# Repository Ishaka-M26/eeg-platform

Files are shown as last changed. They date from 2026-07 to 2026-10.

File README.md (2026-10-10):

# EEG Platform

A custom multichannel EEG acquisition platform for exploring real-time EEG processing and closed-loop neurotechnology.

<p align="center">
  
</p>

**Prototype setup: EEG electrodes, custom ADS1299 interface board, and Zybo Zynq-7000.**

<p align="center">
  
</p>

**Hardware connections and major components of the current prototype.**

# Overview
A custom EEG acquisition platform for real-time neural signal measurement and future closed-loop neurostimulation research.

The system is built around a custom ADS1299-based EEG frontend and a Zynq-based processing platform.  
The current focus is reliable multichannel EEG acquisition, real-time data transfer, and system-level validation from analog input to digital processing.

---

## System Overview

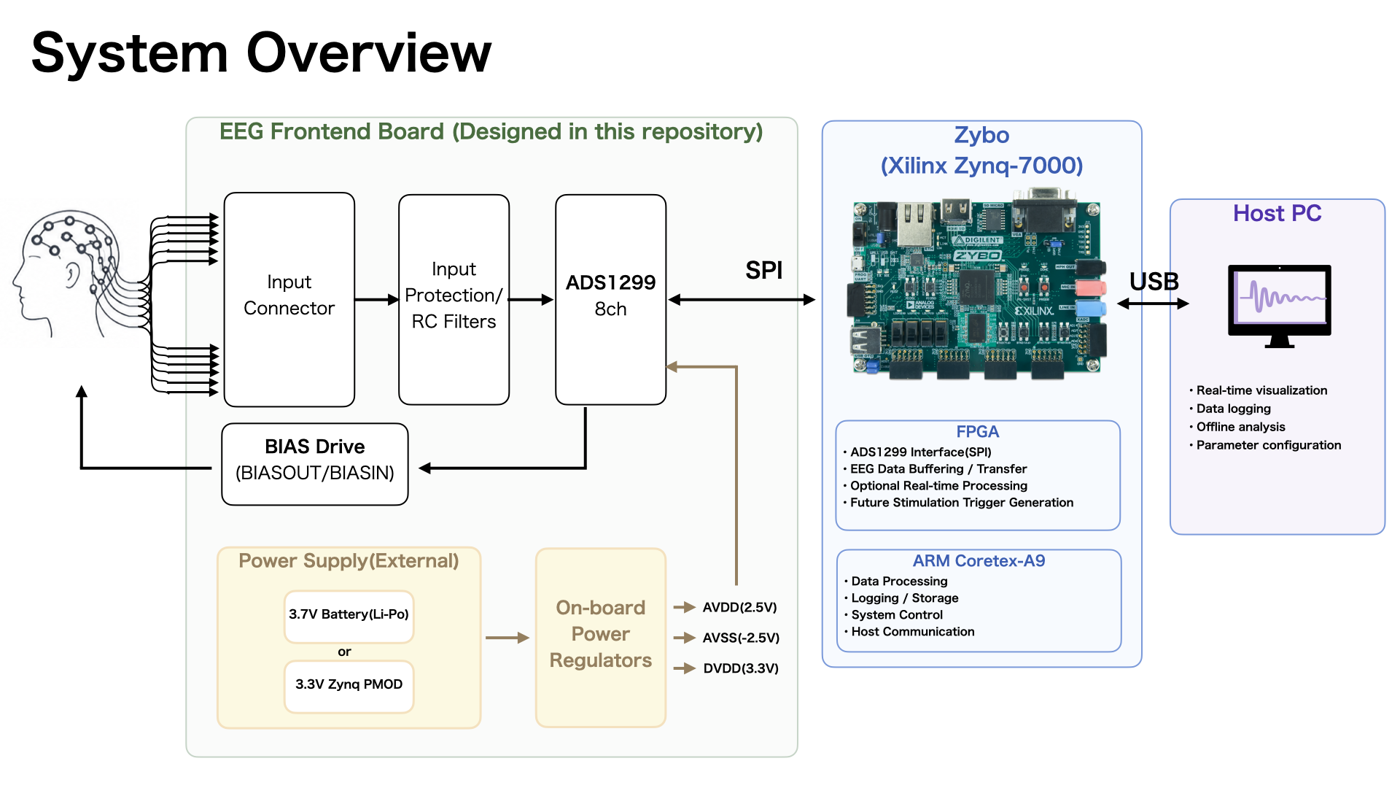
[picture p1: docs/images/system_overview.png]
EEG Platform System Overview


The platform consists of:

- **Custom EEG Frontend Board**
  - ADS1299-based multichannel EEG acquisition
  - Input protection
  - On-board power regulation
  - BIAS / common-mode feedback
  - SPI interface to the processing platform

- **Zybo Z7 / Zynq Platform**
  - ADS1299 SPI interface
  - EEG data reception and transfer
  - Optional real-time processing
  - Future stimulation trigger generation

- **Host PC**
  - Visualization
  - Data logging
  - Offline analysis
  - System configuration

The long-term goal is to extend this platform toward a closed-loop architecture in which brain-state information is estimated in real time and used to control non-invasive stimulation.

---

## Custom EEG Frontend

The EEG frontend board is designed specifically for this project.

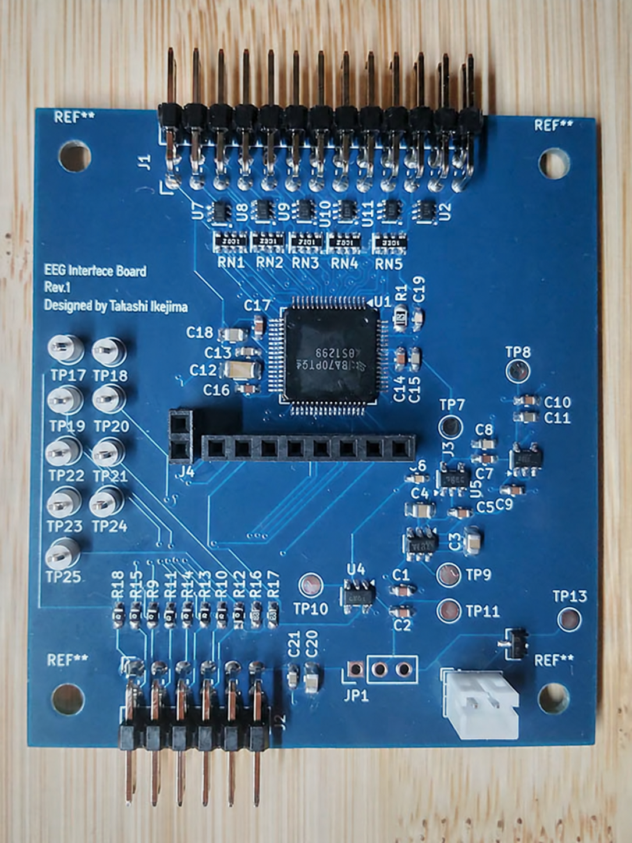
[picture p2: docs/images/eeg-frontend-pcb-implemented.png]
EEG Frontend PCB


It is based on the **ADS1299**, an 8-channel, 24-bit analog front end for biopotential measurement.  
The board integrates EEG input protection, analog acquisition, power regulation, and the digital interface required for connection to the Zynq platform.

The KiCad schematic and PCB design files are available in:

```text
hardware/kicad/eeg-frontend/
```

---

## Project Direction

The project is being developed in stages:

1. **EEG frontend design and fabrication**
2. **Multichannel EEG acquisition**
3. **Zynq-based real-time data handling**
4. **Signal processing and brain-state estimation**
5. **Future closed-loop stimulation integration**

The initial objective is not to build a complete clinical neurostimulation device, but to establish a reliable hardware and software platform for real-time EEG-based neural interface research.

---

## Repository Structure

```text
eeg-platform/
├── docs/
│   └── images/
│       ├── eeg-frontend-3d.png
│       ├── eeg-frontend-pcb.png
│       └── system_overview.png
│
├── hardware/
│   └── kicad/
│       ├── eeg-frontend/
│       └── reference_design/
│
└── README.md
```

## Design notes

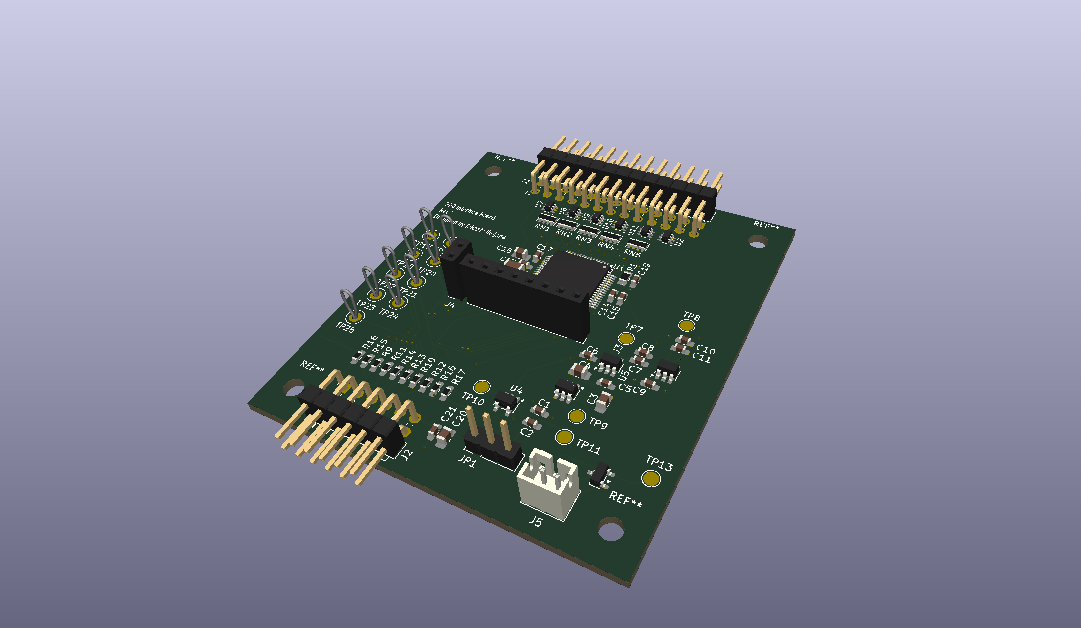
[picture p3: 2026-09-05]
docs/images/eeg-frontend-3d.png

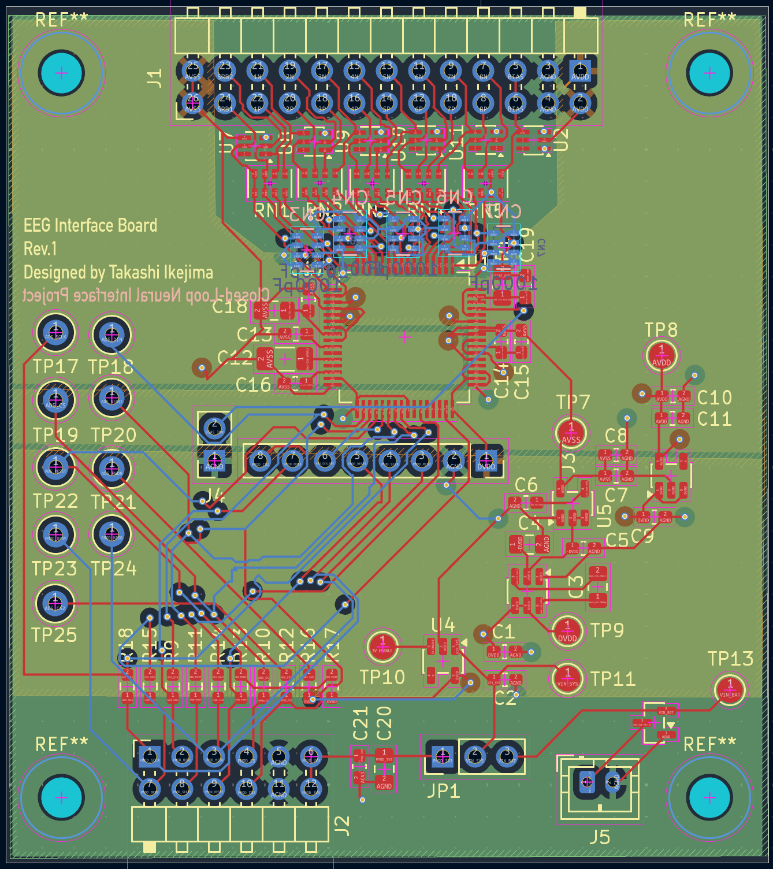
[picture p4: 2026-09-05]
docs/images/eeg-frontend-pcb.png

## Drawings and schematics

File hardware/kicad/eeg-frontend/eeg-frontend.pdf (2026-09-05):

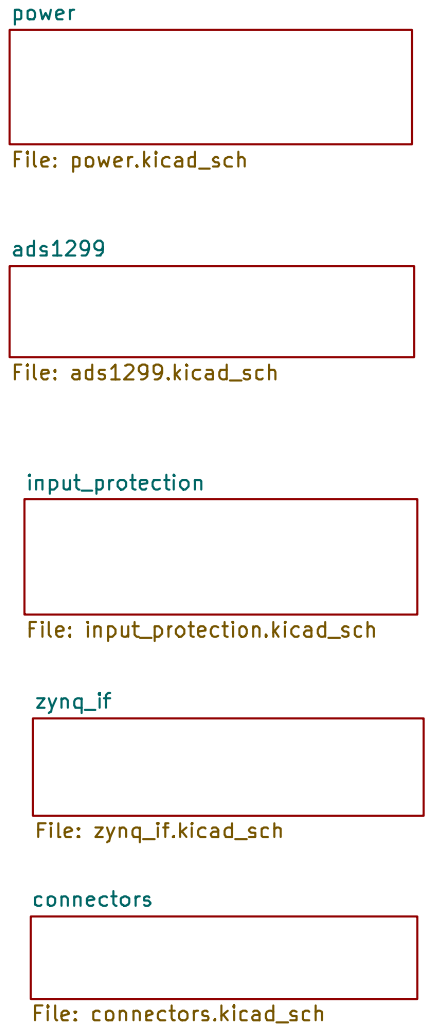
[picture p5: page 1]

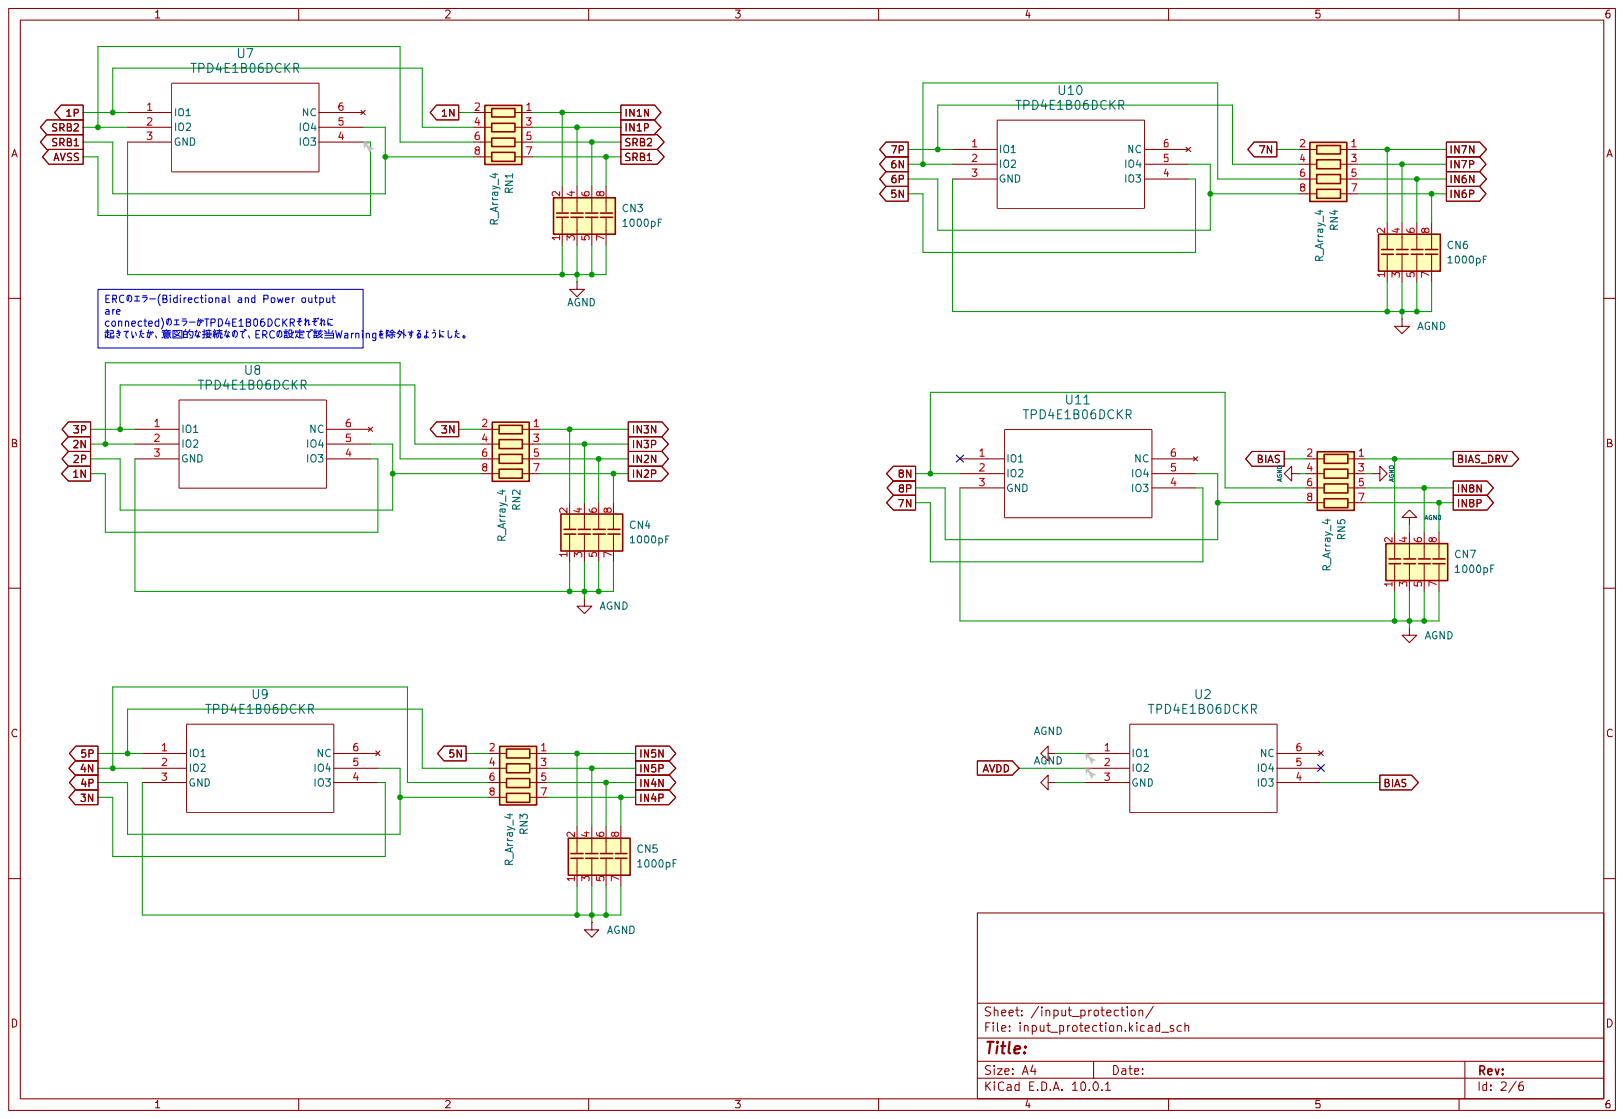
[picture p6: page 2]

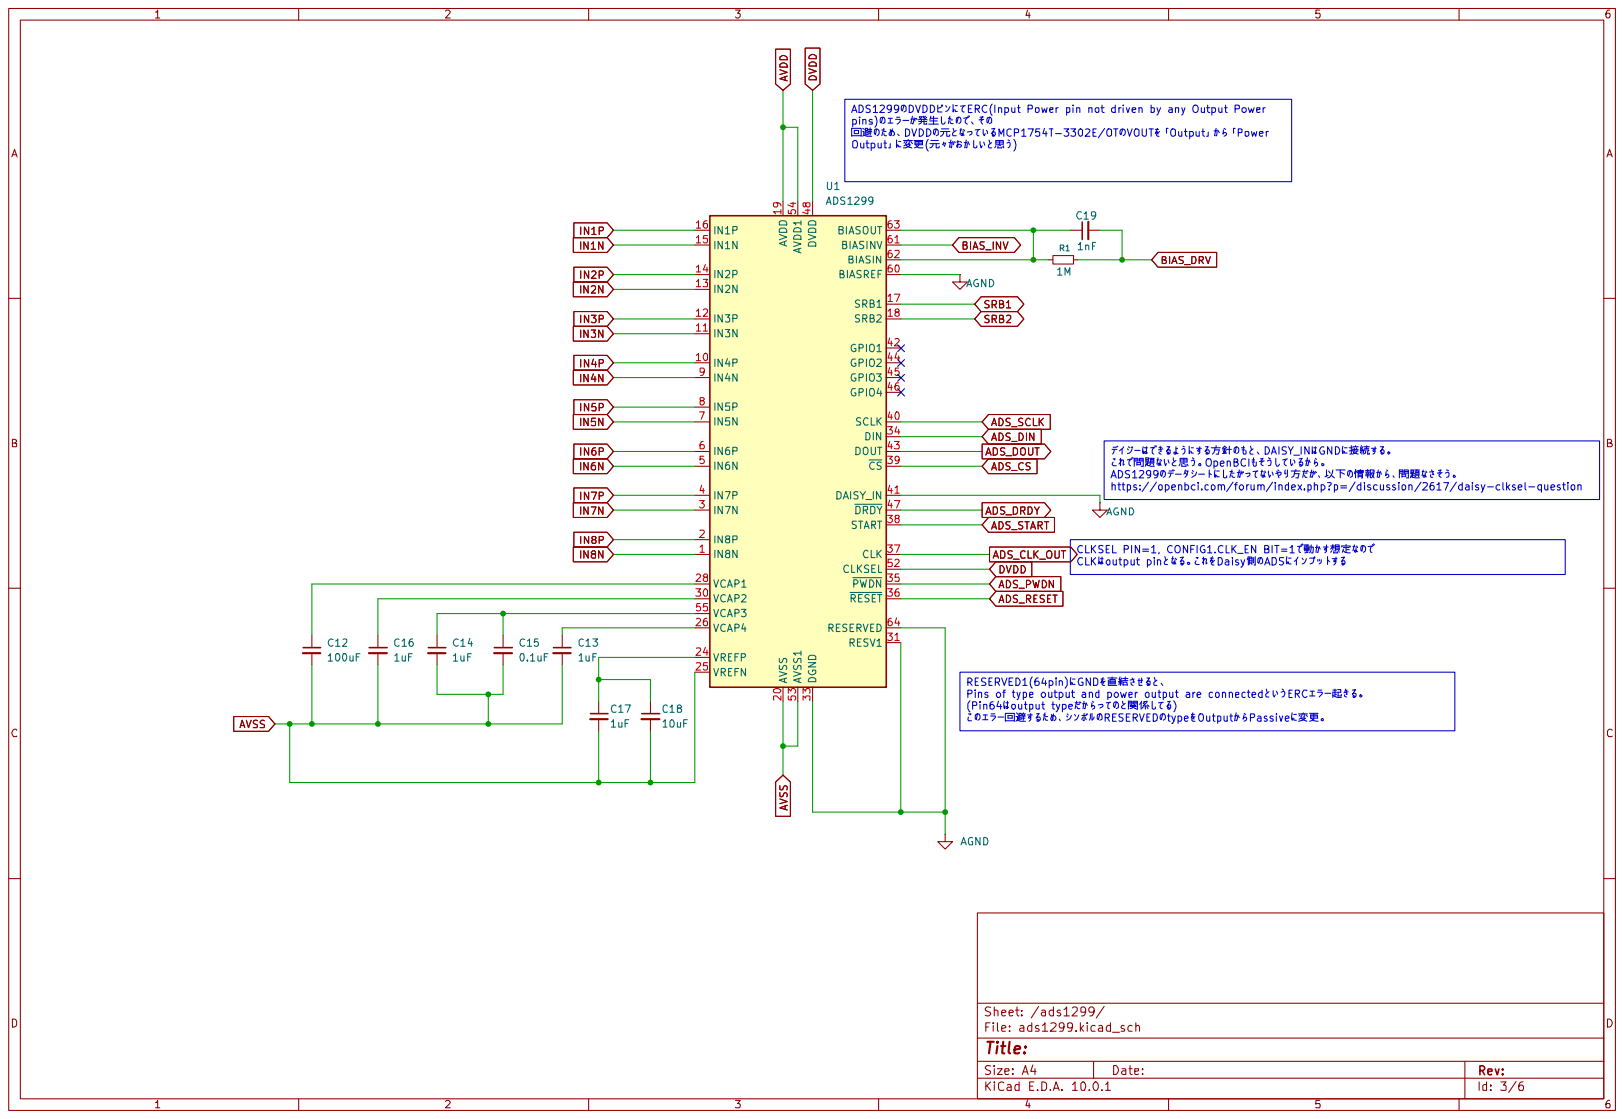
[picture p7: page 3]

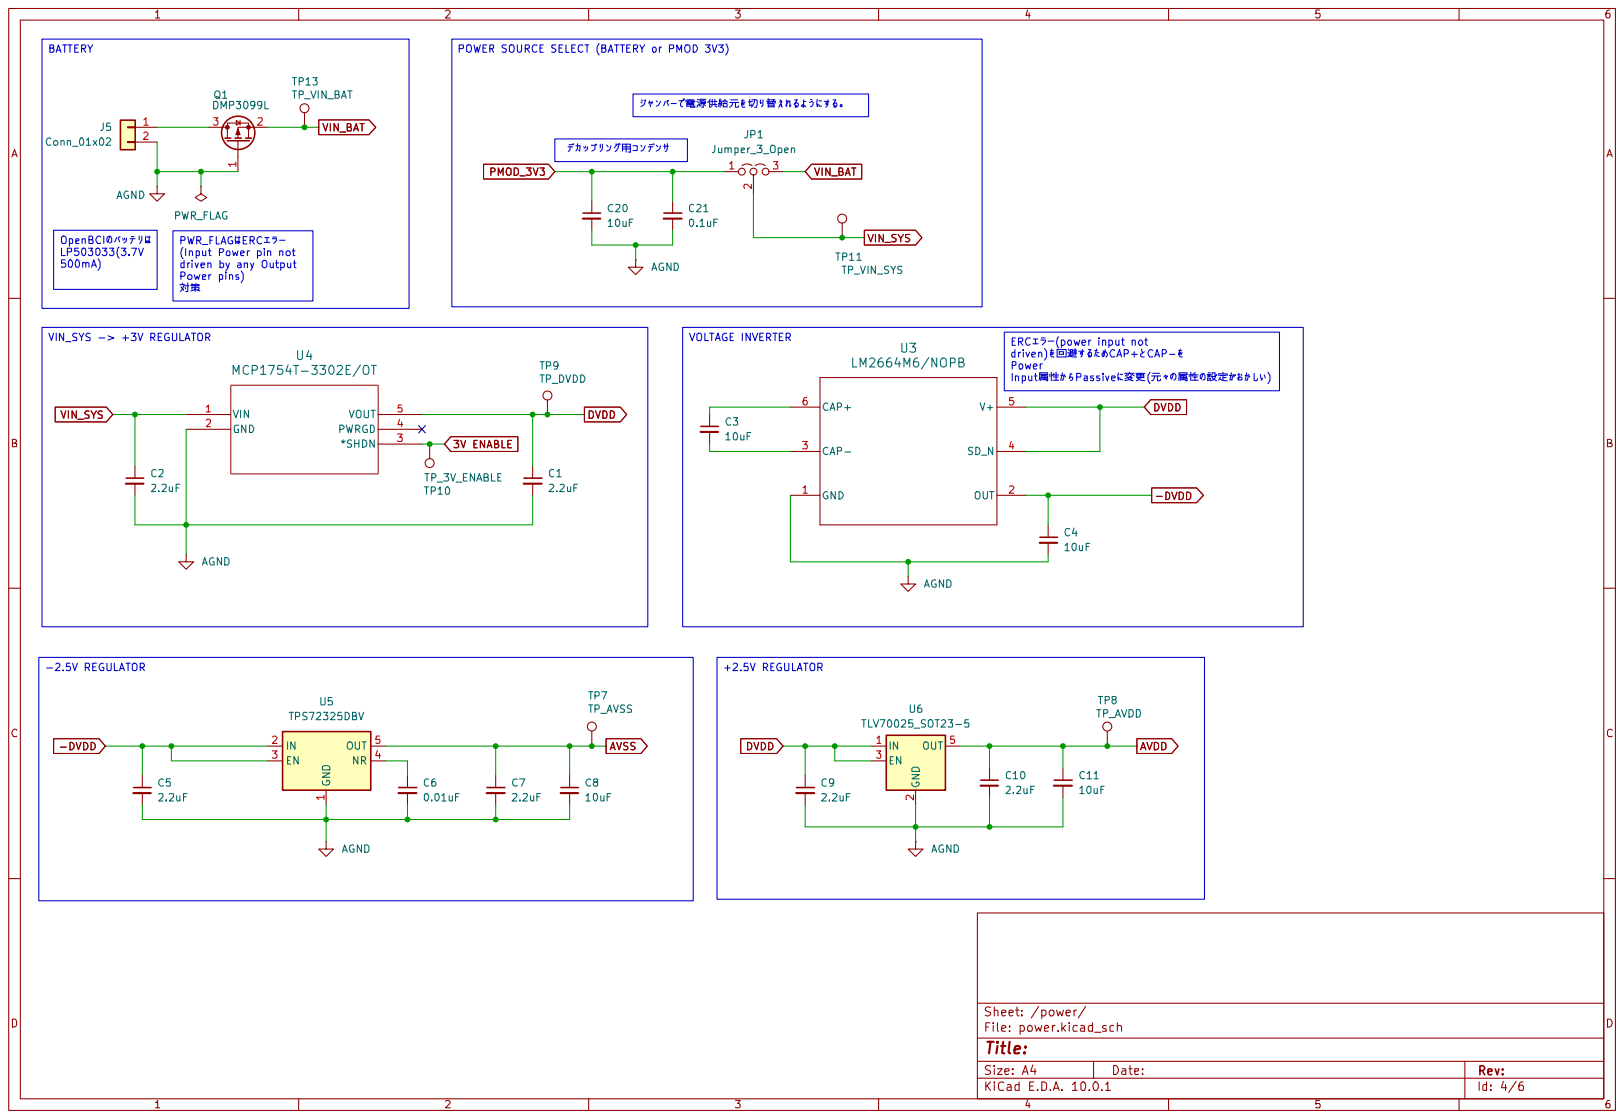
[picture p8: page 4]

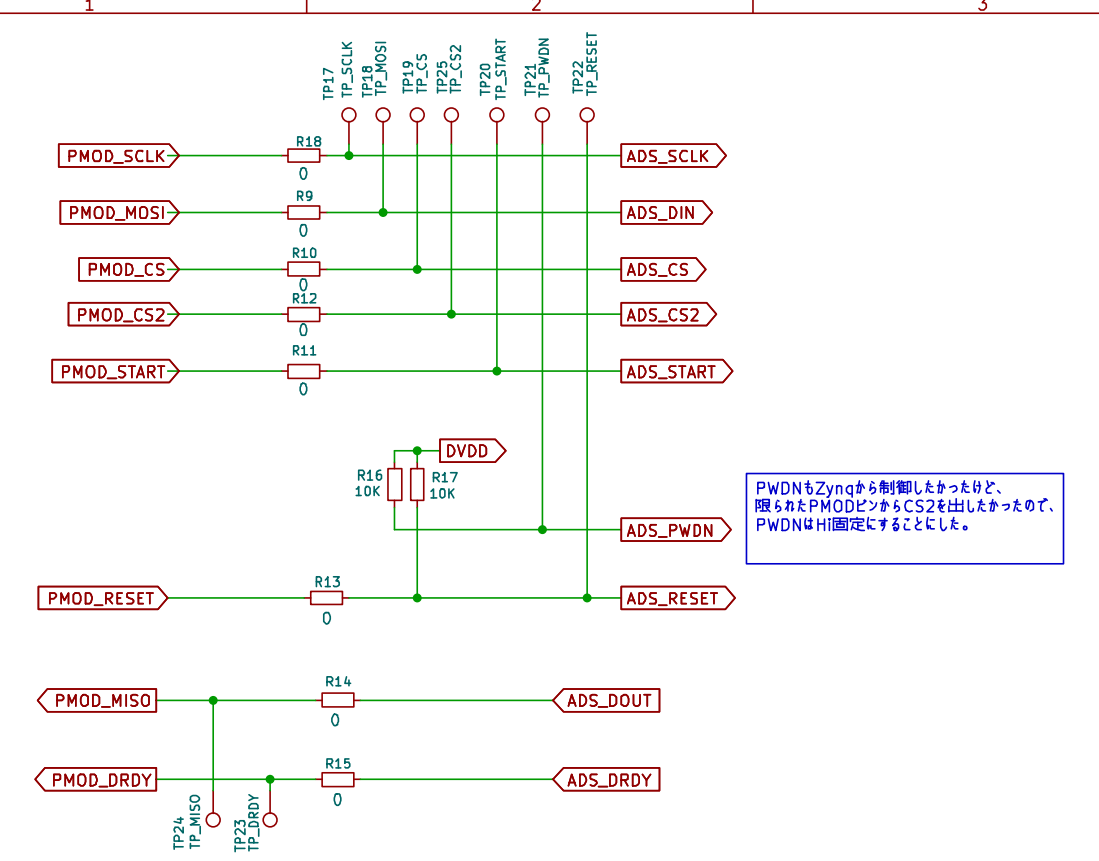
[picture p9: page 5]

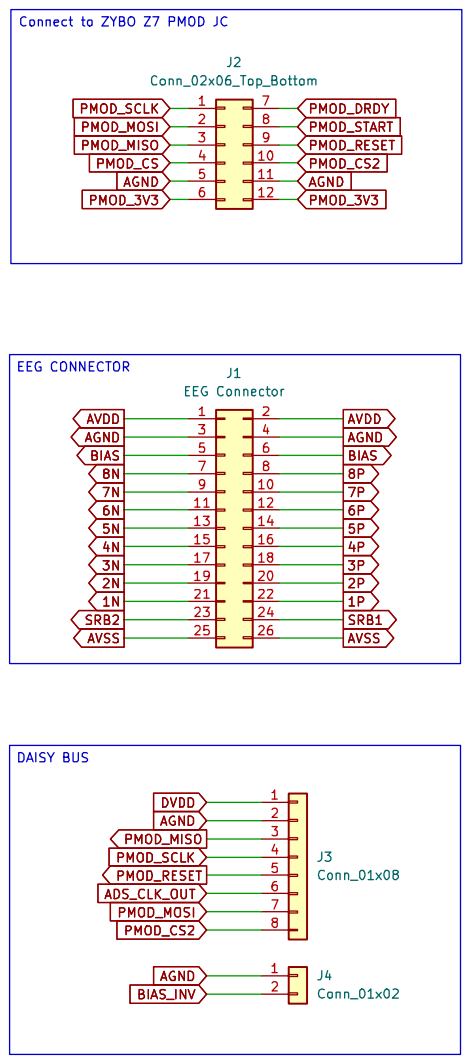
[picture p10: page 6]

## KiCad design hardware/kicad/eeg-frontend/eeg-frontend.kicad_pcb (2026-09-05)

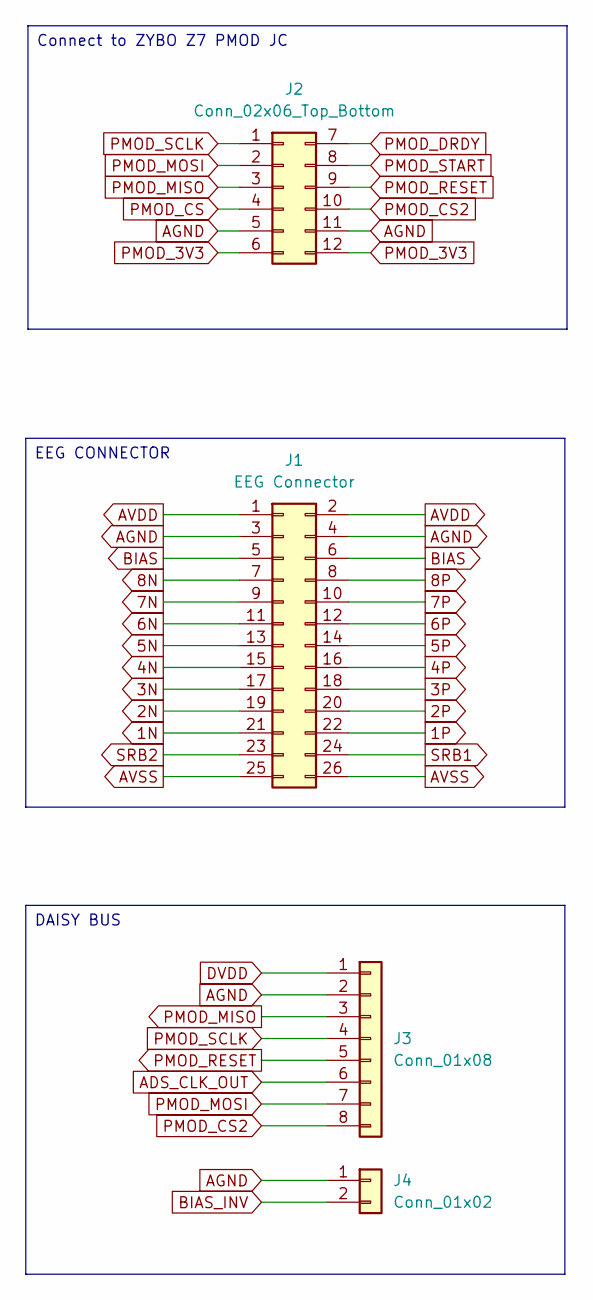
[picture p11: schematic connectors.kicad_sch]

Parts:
J1: EEG Connector; PinHeader_2x13_P2.54mm_Horizontal_mirror
J2: Conn_02x06_Top_Bottom; PinHeader_2x06_P2.54mm_Horizontal_pmod
J3: Conn_01x08; PinSocket_1x08_P2.54mm_Vertical
J4: Conn_01x02; PinSocket_1x02_P2.54mm_Vertical

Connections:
1N: J1.21; also elsewhere on the board
1P: J1.22; also elsewhere on the board
2N: J1.19; also elsewhere on the board
2P: J1.20; also elsewhere on the board
3N: J1.17; also elsewhere on the board
3P: J1.18; also elsewhere on the board
4N: J1.15; also elsewhere on the board
4P: J1.16; also elsewhere on the board
5N: J1.13; also elsewhere on the board
5P: J1.14; also elsewhere on the board
6N: J1.11; also elsewhere on the board
6P: J1.12; also elsewhere on the board
7N: J1.9; also elsewhere on the board
7P: J1.10; also elsewhere on the board
8N: J1.7; also elsewhere on the board
8P: J1.8; also elsewhere on the board
ADS_CLK_OUT: J3.6; also elsewhere on the board
AGND: J1.3, J1.4, J2.5, J2.11, J3.2, J4.1; also elsewhere on the board
AVDD: J1.1, J1.2; also elsewhere on the board
AVSS: J1.25, J1.26; also elsewhere on the board
BIAS: J1.5, J1.6; also elsewhere on the board
BIAS_INV: J4.2; also elsewhere on the board
DVDD: J3.1; also elsewhere on the board
PMOD_3V3: J2.6, J2.12; also elsewhere on the board
PMOD_CS: J2.4; also elsewhere on the board
PMOD_CS2: J2.10, J3.8; also elsewhere on the board
PMOD_DRDY: J2.7; also elsewhere on the board
PMOD_MISO: J2.3, J3.3; also elsewhere on the board
PMOD_MOSI: J2.2, J3.7; also elsewhere on the board
PMOD_RESET: J2.9, J3.5; also elsewhere on the board
PMOD_SCLK: J2.1, J3.4; also elsewhere on the board
PMOD_START: J2.8; also elsewhere on the board
SRB1: J1.24; also elsewhere on the board
SRB2: J1.23; also elsewhere on the board

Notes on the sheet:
Connect to ZYBO Z7 PMOD JC
DAISY BUS
EEG CONNECTOR

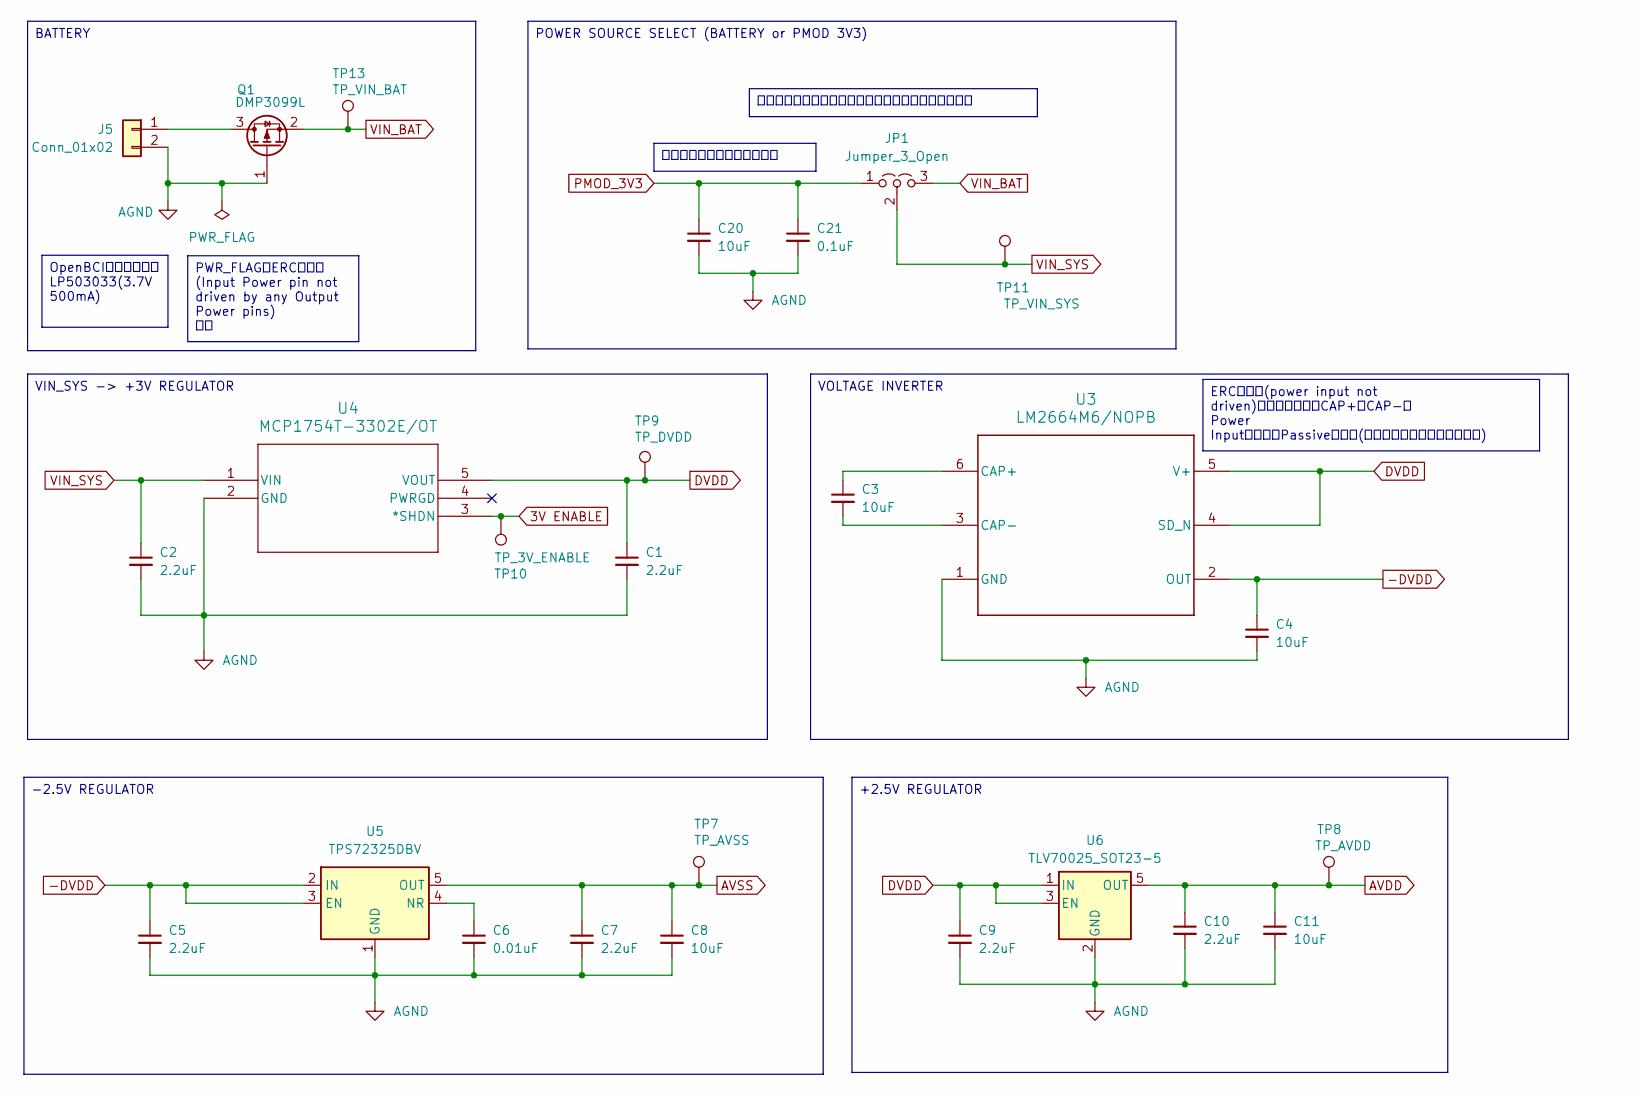
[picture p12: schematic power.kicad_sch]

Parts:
C1, C2, C5, C7, C9, C10: 2.2uF; C_0603_1608Metric_Pad1.08x0.95mm_HandSolder
C3, C4, C20: 10uF; C_0805_2012Metric_Pad1.18x1.45mm_HandSolder
C6: 0.01uF; C_0603_1608Metric_Pad1.08x0.95mm_HandSolder
C8, C11: 10uF; C_0603_1608Metric_Pad1.08x0.95mm_HandSolder
C21: 0.1uF; C_0603_1608Metric_Pad1.08x0.95mm_HandSolder
J5: Conn_01x02; JST_PH_B2B-PH-K_1x02_P2.00mm_Vertical
JP1: Jumper_3_Open; PinHeader_1x03_P2.54mm_Vertical
Q1: DMP3099L; SOT-23
TP7: TP_AVSS; TestPoint_Pad_D2.0mm
TP8: TP_AVDD; TestPoint_Pad_D2.0mm
TP9: TP_DVDD; TestPoint_Pad_D2.0mm
TP10: TP_3V_ENABLE; TestPoint_Pad_D2.0mm
TP11: TP_VIN_SYS; TestPoint_Pad_D2.0mm
TP13: TP_VIN_BAT; TestPoint_Pad_D2.0mm
U3: LM2664M6/NOPB; SOT-23-6
U4: MCP1754T-3302E/OT; SOT-23-5
U5: TPS72325DBV; SOT-23-5
U6: TLV70025_SOT23-5; SOT-23-5

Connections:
3V ENABLE: TP10.1 (1_1), U4.3 (*SHDN)
-DVDD: C4.1, C5.1, U3.2 (OUT), U5.2 (IN), U5.3 (EN)
AGND: C1.2, C2.2, C4.2, C5.2, C6.2, C7.2, C8.2, C9.2, C10.2, C11.2, C20.2, C21.2, J5.2, Q1.1 (G), U3.1 (GND), U4.2 (GND), U5.1 (GND), U6.2 (GND); also elsewhere on the board
AVDD: C10.1, C11.1, TP8.1 (1_1), U6.5 (OUT); also elsewhere on the board
AVSS: C7.1, C8.1, TP7.1 (1_1), U5.5 (OUT); also elsewhere on the board
DVDD: C1.1, C9.1, TP9.1 (1_1), U3.4 (SD_N), U3.5 (V+), U4.5 (VOUT), U6.1 (IN), U6.3 (EN); also elsewhere on the board
unnamed: J5.1, Q1.3 (D)
unnamed: C3.1, U3.6 (CAP+)
unnamed: C3.2, U3.3 (CAP-)
unnamed: C6.1, U5.4 (NR)
PMOD_3V3: C20.1, C21.1, JP1.1 (A); also elsewhere on the board
VIN_BAT: JP1.3 (B), Q1.2 (S), TP13.1 (1_1)
VIN_SYS: C2.1, JP1.2 (C), TP11.1 (1_1), U4.1 (VIN)

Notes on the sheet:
PWR_FLAGはERCエラー (Input Power pin not driven by any Output Power pins) 対策
デカップリング用コンデンサ
ERCエラー(power input not driven)を回避するためCAP+とCAP-を Power Input属性からPassiveに変更(元々の属性の設定がおかしい)
VOLTAGE INVERTER
BATTERY
+2.5V REGULATOR
POWER SOURCE SELECT (BATTERY or PMOD 3V3)
-2.5V REGULATOR
ジャンパーで電源供給元を切り替えれるようにする。
OpenBCIのバッテリは LP503033(3.7V 500mA)
VIN_SYS -> +3V REGULATOR

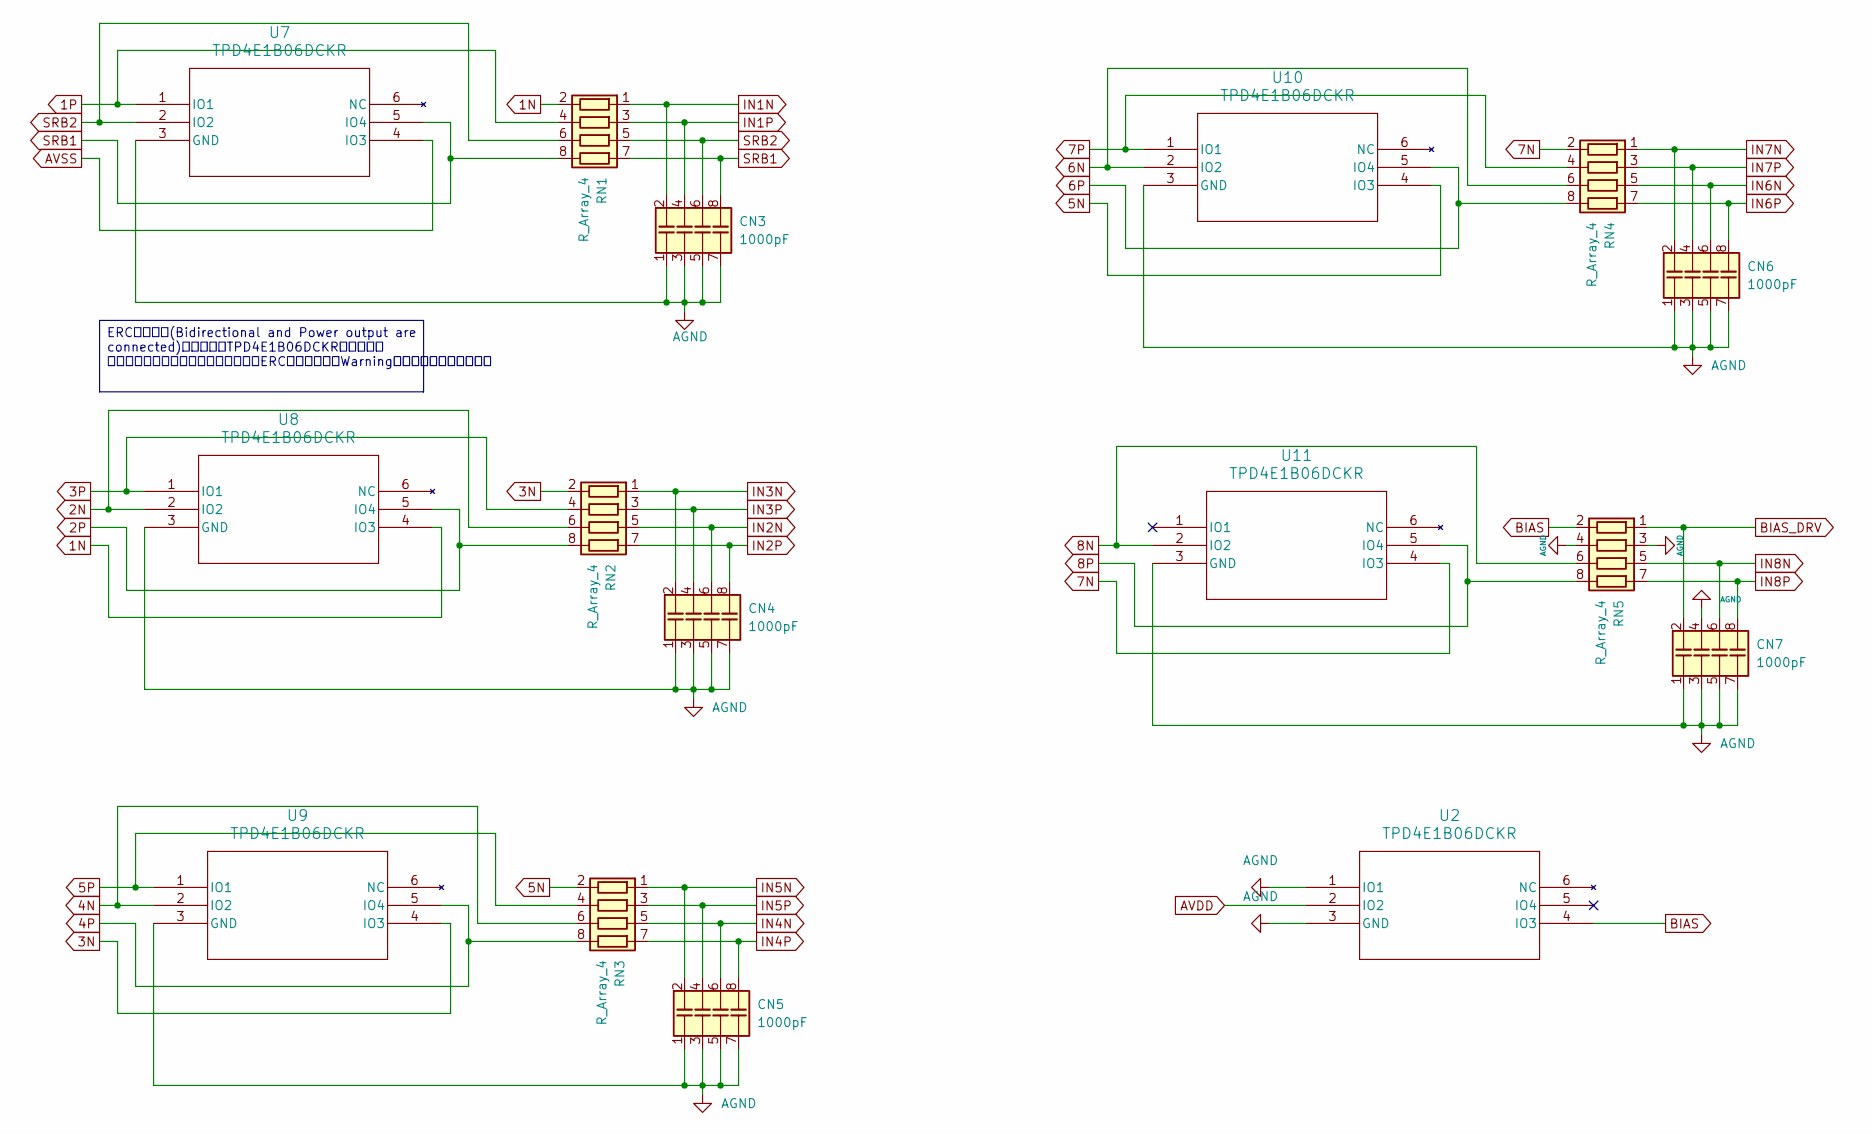
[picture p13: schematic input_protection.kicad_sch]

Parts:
CN3, CN4, CN5, CN6, CN7: 1000pF; C_Array_Convex_4x0612
RN1, RN2, RN3, RN4, RN5: R_Array_4; R_Cat16-4
U2, U7, U8, U9, U10, U11: TPD4E1B06DCKR; SOT-363_SC-70-6

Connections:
1N: RN1.2 (R1), U8.4 (IO3); also elsewhere on the board
1P: RN1.4 (R2), U7.1 (IO1); also elsewhere on the board
2N: RN2.6 (R3), U8.2 (IO2); also elsewhere on the board
2P: RN2.8 (R4), U8.5 (IO4); also elsewhere on the board
3N: RN2.2 (R1), U9.4 (IO3); also elsewhere on the board
3P: RN2.4 (R2), U8.1 (IO1); also elsewhere on the board
4N: RN3.6 (R3), U9.2 (IO2); also elsewhere on the board
4P: RN3.8 (R4), U9.5 (IO4); also elsewhere on the board
5N: RN3.2 (R1), U10.4 (IO3); also elsewhere on the board
5P: RN3.4 (R2), U9.1 (IO1); also elsewhere on the board
6N: RN4.6 (R3), U10.2 (IO2); also elsewhere on the board
6P: RN4.8 (R4), U10.5 (IO4); also elsewhere on the board
7N: RN4.2 (R1), U11.4 (IO3); also elsewhere on the board
7P: RN4.4 (R2), U10.1 (IO1); also elsewhere on the board
8N: RN5.6 (R3), U11.2 (IO2); also elsewhere on the board
8P: RN5.8 (R4), U11.5 (IO4); also elsewhere on the board
AGND: CN3.1 (common), CN3.3 (common), CN3.5 (common), CN3.7 (common), CN4.1 (common), CN4.3 (common), CN4.5 (common), CN4.7 (common), CN5.1 (common), CN5.3 (common), CN5.5 (common), CN5.7 (common), CN6.1 (common), CN6.3 (common), CN6.5 (common), CN6.7 (common), CN7.1 (common), CN7.3 (common), CN7.4 (C2), CN7.5 (common), CN7.7 (common), RN5.3 (common), RN5.4 (R2), U2.1 (IO1), U2.3 (GND), U7.3 (GND), U8.3 (GND), U9.3 (GND), U10.3 (GND), U11.3 (GND); also elsewhere on the board
AVDD: U2.2 (IO2); also elsewhere on the board
AVSS: U7.4 (IO3); also elsewhere on the board
BIAS: RN5.2 (R1), U2.4 (IO3); also elsewhere on the board
BIAS_DRV: CN7.2 (C1), RN5.1 (common); also elsewhere on the board
IN1N: CN3.2 (C1), RN1.1 (common); also elsewhere on the board
IN1P: CN3.4 (C2), RN1.3 (common); also elsewhere on the board
IN2N: CN4.6 (C3), RN2.5 (common); also elsewhere on the board
IN2P: CN4.8 (C4), RN2.7 (common); also elsewhere on the board
IN3N: CN4.2 (C1), RN2.1 (common); also elsewhere on the board
IN3P: CN4.4 (C2), RN2.3 (common); also elsewhere on the board
IN4N: CN5.6 (C3), RN3.5 (common); also elsewhere on the board
IN4P: CN5.8 (C4), RN3.7 (common); also elsewhere on the board
IN5N: CN5.2 (C1), RN3.1 (common); also elsewhere on the board
IN5P: CN5.4 (C2), RN3.3 (common); also elsewhere on the board
IN6N: CN6.6 (C3), RN4.5 (common); also elsewhere on the board
IN6P: CN6.8 (C4), RN4.7 (common); also elsewhere on the board
IN7N: CN6.2 (C1), RN4.1 (common); also elsewhere on the board
IN7P: CN6.4 (C2), RN4.3 (common); also elsewhere on the board
IN8N: CN7.6 (C3), RN5.5 (common); also elsewhere on the board
IN8P: CN7.8 (C4), RN5.7 (common); also elsewhere on the board
SRB1: CN3.8 (C4), RN1.7 (common), RN1.8 (R4), U7.5 (IO4); also elsewhere on the board
SRB2: CN3.6 (C3), RN1.5 (common), RN1.6 (R3), U7.2 (IO2); also elsewhere on the board

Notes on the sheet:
ERCのエラー(Bidirectional and Power output are connected)のエラーがTPD4E1B06DCKRそれぞれに 起きていたが、意図的な接続なので、ERCの設定で該当Warningを除外するようにした。

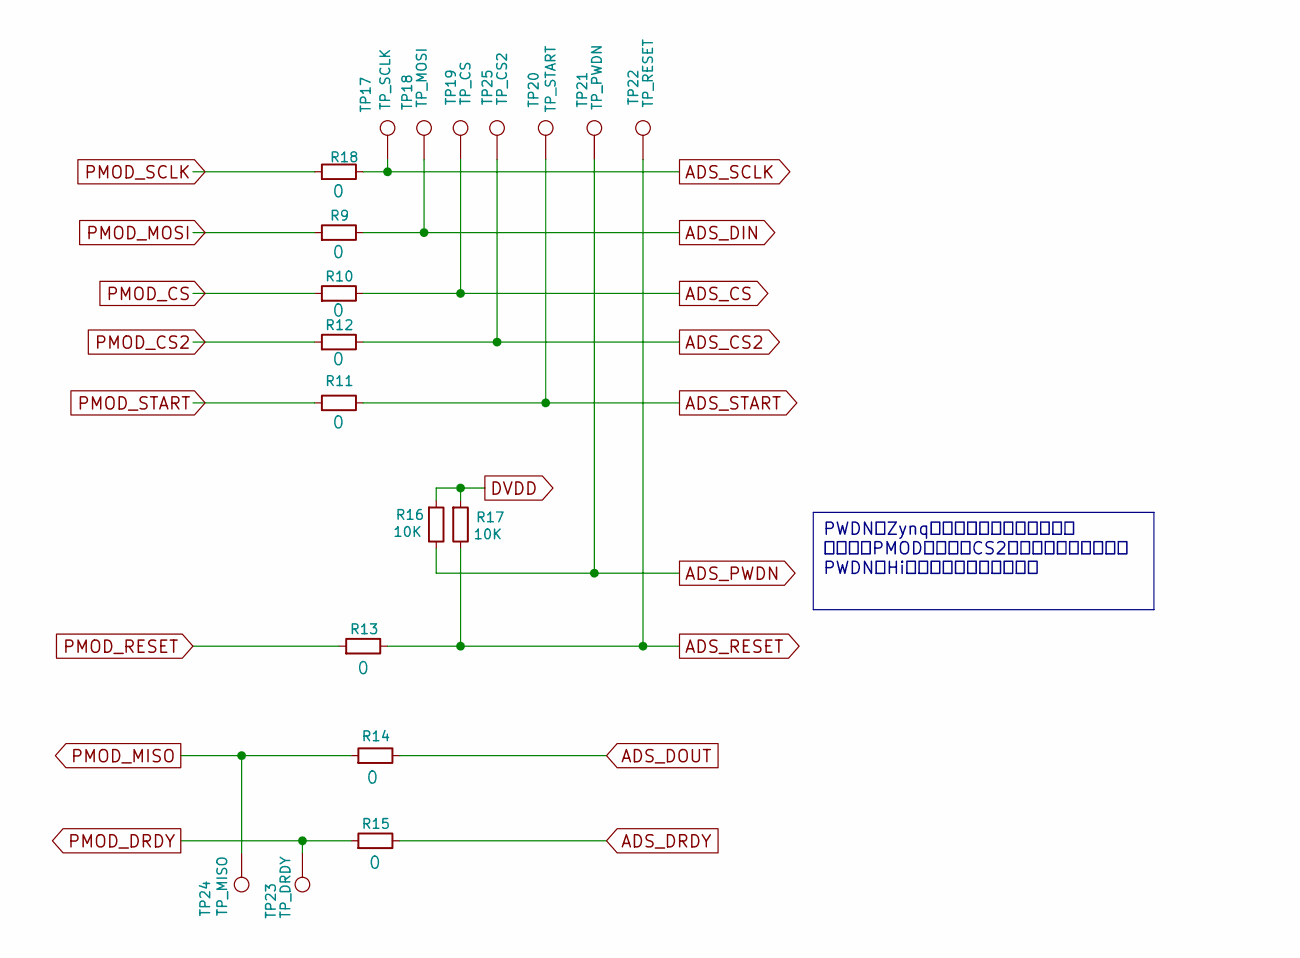
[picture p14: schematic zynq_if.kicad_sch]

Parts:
R9, R10, R11, R12, R13, R14, R15, R18: 0; R_0603_1608Metric_Pad0.98x0.95mm_HandSolder
R16, R17: 10K; R_0603_1608Metric_Pad0.98x0.95mm_HandSolder
TP17: TP_SCLK; TestPoint_Loop_D2.50mm_Drill1.0mm
TP18: TP_MOSI; TestPoint_Loop_D2.50mm_Drill1.0mm
TP19: TP_CS; TestPoint_Loop_D2.50mm_Drill1.0mm
TP20: TP_START; TestPoint_Loop_D2.50mm_Drill1.0mm
TP21: TP_PWDN; TestPoint_Loop_D2.50mm_Drill1.0mm
TP22: TP_RESET; TestPoint_Loop_D2.50mm_Drill1.0mm
TP23: TP_DRDY; TestPoint_Loop_D2.50mm_Drill1.0mm
TP24: TP_MISO; TestPoint_Loop_D2.50mm_Drill1.0mm
TP25: TP_CS2; TestPoint_Loop_D2.50mm_Drill1.0mm

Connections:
ADS_CS: R10.2, TP19.1 (1_1); also elsewhere on the board
ADS_CS2: R12.2, TP25.1 (1_1)
ADS_DIN: R9.2, TP18.1 (1_1); also elsewhere on the board
ADS_DOUT: R14.2; also elsewhere on the board
ADS_DRDY: R15.2; also elsewhere on the board
ADS_PWDN: R16.2, TP21.1 (1_1); also elsewhere on the board
ADS_RESET: R13.2, R17.2, TP22.1 (1_1); also elsewhere on the board
ADS_SCLK: R18.2, TP17.1 (1_1); also elsewhere on the board
ADS_START: R11.2, TP20.1 (1_1); also elsewhere on the board
DVDD: R16.1, R17.1; also elsewhere on the board
PMOD_CS: R10.1; also elsewhere on the board
PMOD_CS2: R12.1; also elsewhere on the board
PMOD_DRDY: R15.1, TP23.1 (1_1); also elsewhere on the board
PMOD_MISO: R14.1, TP24.1 (1_1); also elsewhere on the board
PMOD_MOSI: R9.1; also elsewhere on the board
PMOD_RESET: R13.1; also elsewhere on the board
PMOD_SCLK: R18.1; also elsewhere on the board
PMOD_START: R11.1; also elsewhere on the board

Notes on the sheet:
PWDNもZynqから制御したかったけど、 限られたPMODピンからCS2を出したかったので、 PWDNはHi固定にすることにした。

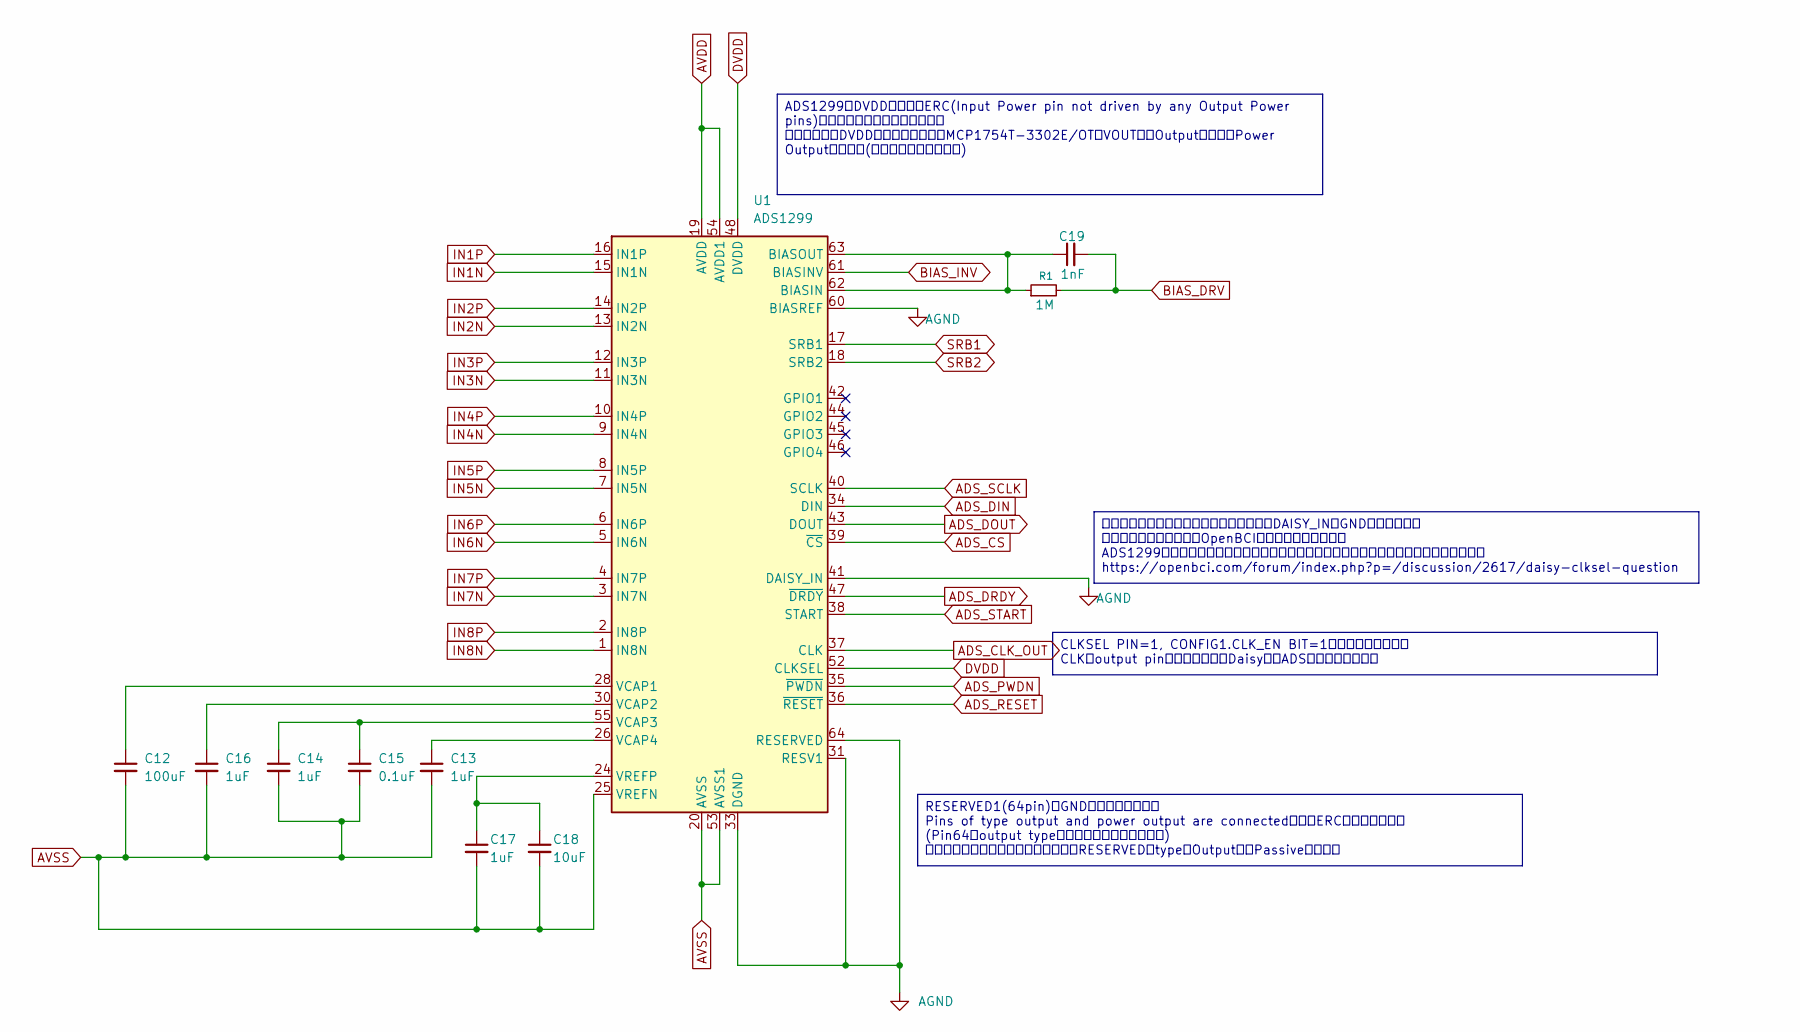
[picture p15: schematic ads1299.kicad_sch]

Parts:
C12: 100uF; C_1206_3216Metric_Pad1.33x1.80mm_HandSolder
C13, C14, C16, C17: 1uF; C_0603_1608Metric_Pad1.08x0.95mm_HandSolder
C15: 0.1uF; C_0603_1608Metric_Pad1.08x0.95mm_HandSolder
C18: 10uF; C_0805_2012Metric_Pad1.18x1.45mm_HandSolder
C19: 1nF; C_0603_1608Metric_Pad1.08x0.95mm_HandSolder
R1: 1M; R_0805_2012Metric_Pad1.20x1.40mm_HandSolder
U1: ADS1299; TQFP-64_10x10mm_P0.5mm

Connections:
ADS_CLK_OUT: U1.37 (CLK); also elsewhere on the board
ADS_CS: U1.39 (~CS); also elsewhere on the board
ADS_DIN: U1.34 (DIN); also elsewhere on the board
ADS_DOUT: U1.43 (DOUT); also elsewhere on the board
ADS_DRDY: U1.47 (~DRDY); also elsewhere on the board
ADS_PWDN: U1.35 (~PWDN); also elsewhere on the board
ADS_RESET: U1.36 (~RESET); also elsewhere on the board
ADS_SCLK: U1.40 (SCLK); also elsewhere on the board
ADS_START: U1.38 (START); also elsewhere on the board
AGND: U1.31 (RESV1), U1.33 (DGND), U1.41 (DAISY_IN), U1.49 (DGND), U1.51 (DGND), U1.60 (BIASREF), U1.64 (RESERVED); also elsewhere on the board
AVDD: U1.19 (AVDD), U1.21 (AVDD), U1.22 (AVDD), U1.54 (AVDD1), U1.56 (AVDD), U1.59 (AVDD); also elsewhere on the board
AVSS: C12.2, C13.2, C14.2, C15.2, C16.2, C17.2, C18.2, U1.20 (AVSS), U1.23 (AVSS), U1.25 (VREFN), U1.32 (AVSS), U1.53 (AVSS1), U1.57 (AVSS), U1.58 (AVSS); also elsewhere on the board
BIAS_DRV: C19.2, R1.2; also elsewhere on the board
BIAS_INV: U1.61 (BIASINV); also elsewhere on the board
DVDD: U1.48 (DVDD), U1.50 (DVDD), U1.52 (CLKSEL); also elsewhere on the board
IN1N: U1.15 (IN1N); also elsewhere on the board
IN1P: U1.16 (IN1P); also elsewhere on the board
IN2N: U1.13 (IN2N); also elsewhere on the board
IN2P: U1.14 (IN2P); also elsewhere on the board
IN3N: U1.11 (IN3N); also elsewhere on the board
IN3P: U1.12 (IN3P); also elsewhere on the board
IN4N: U1.9 (IN4N); also elsewhere on the board
IN4P: U1.10 (IN4P); also elsewhere on the board
IN5N: U1.7 (IN5N); also elsewhere on the board
IN5P: U1.8 (IN5P); also elsewhere on the board
IN6N: U1.5 (IN6N); also elsewhere on the board
IN6P: U1.6 (IN6P); also elsewhere on the board
IN7N: U1.3 (IN7N); also elsewhere on the board
IN7P: U1.4 (IN7P); also elsewhere on the board
IN8N: U1.1 (IN8N); also elsewhere on the board
IN8P: U1.2 (IN8P); also elsewhere on the board
unnamed: C19.1, R1.1, U1.62 (BIASIN), U1.63 (BIASOUT)
unnamed: C12.1, U1.28 (VCAP1)
unnamed: C16.1, U1.30 (VCAP2)
unnamed: C14.1, C15.1, U1.55 (VCAP3)
unnamed: C13.1, U1.26 (VCAP4)
unnamed: C17.1, C18.1, U1.24 (VREFP)
SRB1: U1.17 (SRB1); also elsewhere on the board
SRB2: U1.18 (SRB2); also elsewhere on the board

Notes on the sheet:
ADS1299のDVDDピンにてERC(Input Power pin not driven by any Output Power pins)のエラーが発生したので、その 回避のため、DVDDの元となっているMCP1754T-3302E/OTのVOUTを「Output」から「Power Output」に変更(元々がおかしいと思う)
RESERVED1(64pin)にGNDを直結させると、 Pins of type output and power output are connectedというERCエラー起きる。 (Pin64はoutput typeだからってのと関係してる) このエラー回避するため、シンボルのRESERVEDのtypeをOutputからPassiveに変更。
CLKSEL PIN=1, CONFIG1.CLK_EN BIT=1で動かす想定なので CLKはoutput pinとなる。これをDaisy側のADSにインプットする
デイジーはできるようにする方針のもと、DAISY_INはGNDに接続する。 これで問題ないと思う。OpenBCIもそうしているから。 ADS1299のデータシートにしたがってないやり方だが、以下の情報から、問題なさそう。 https://openbci.com/forum/index.php?p=/discussion/2617/daisy-clksel-question

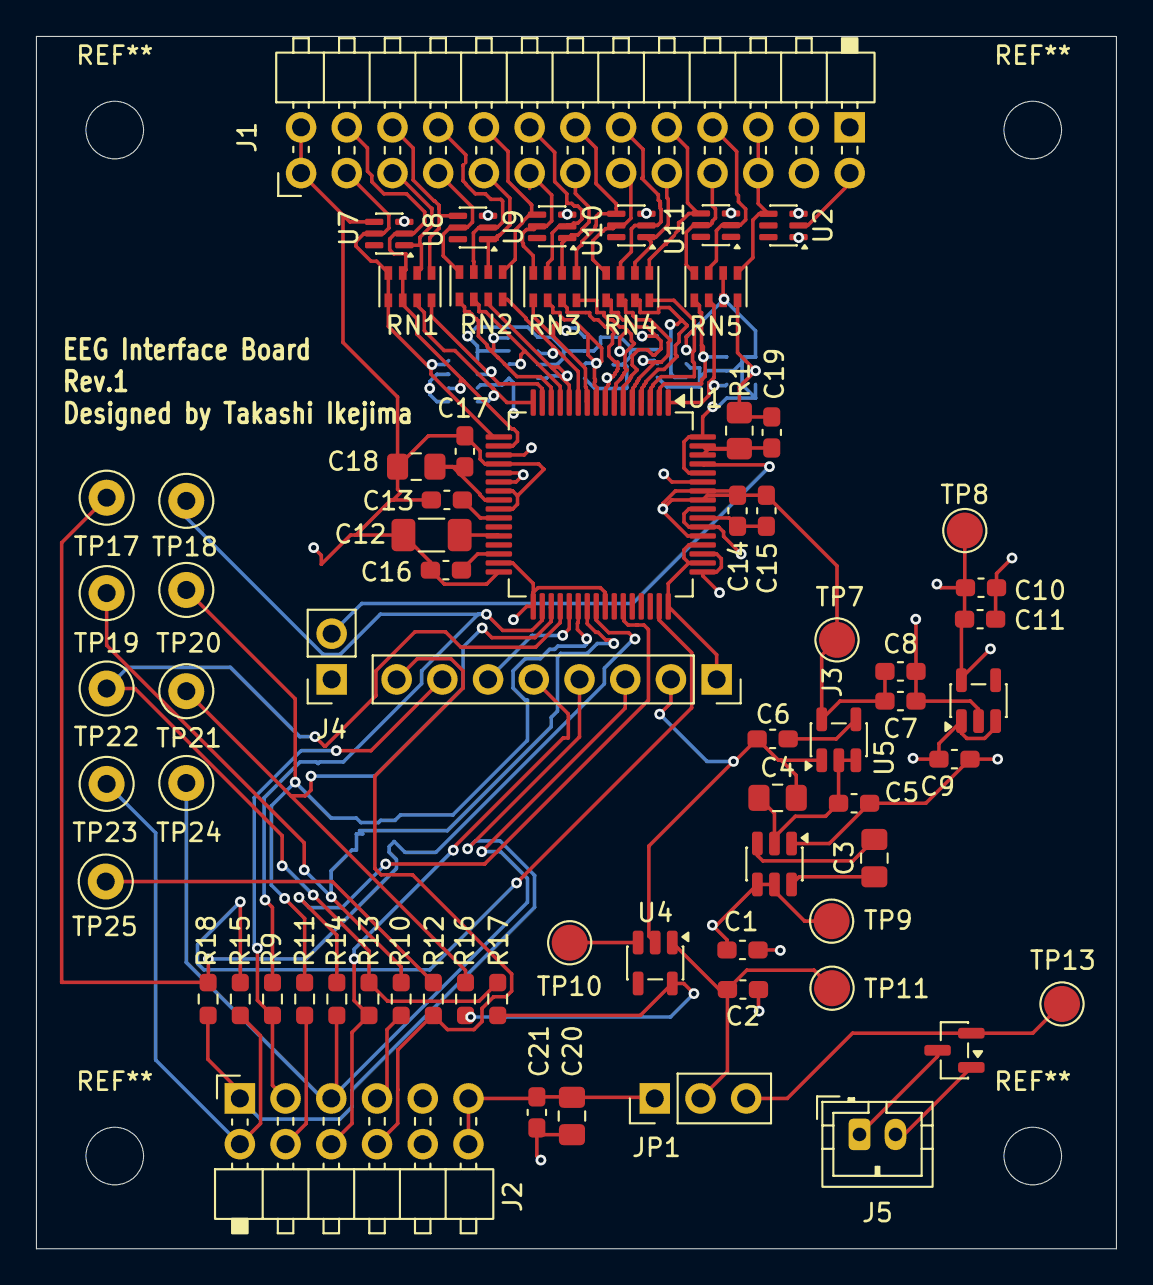
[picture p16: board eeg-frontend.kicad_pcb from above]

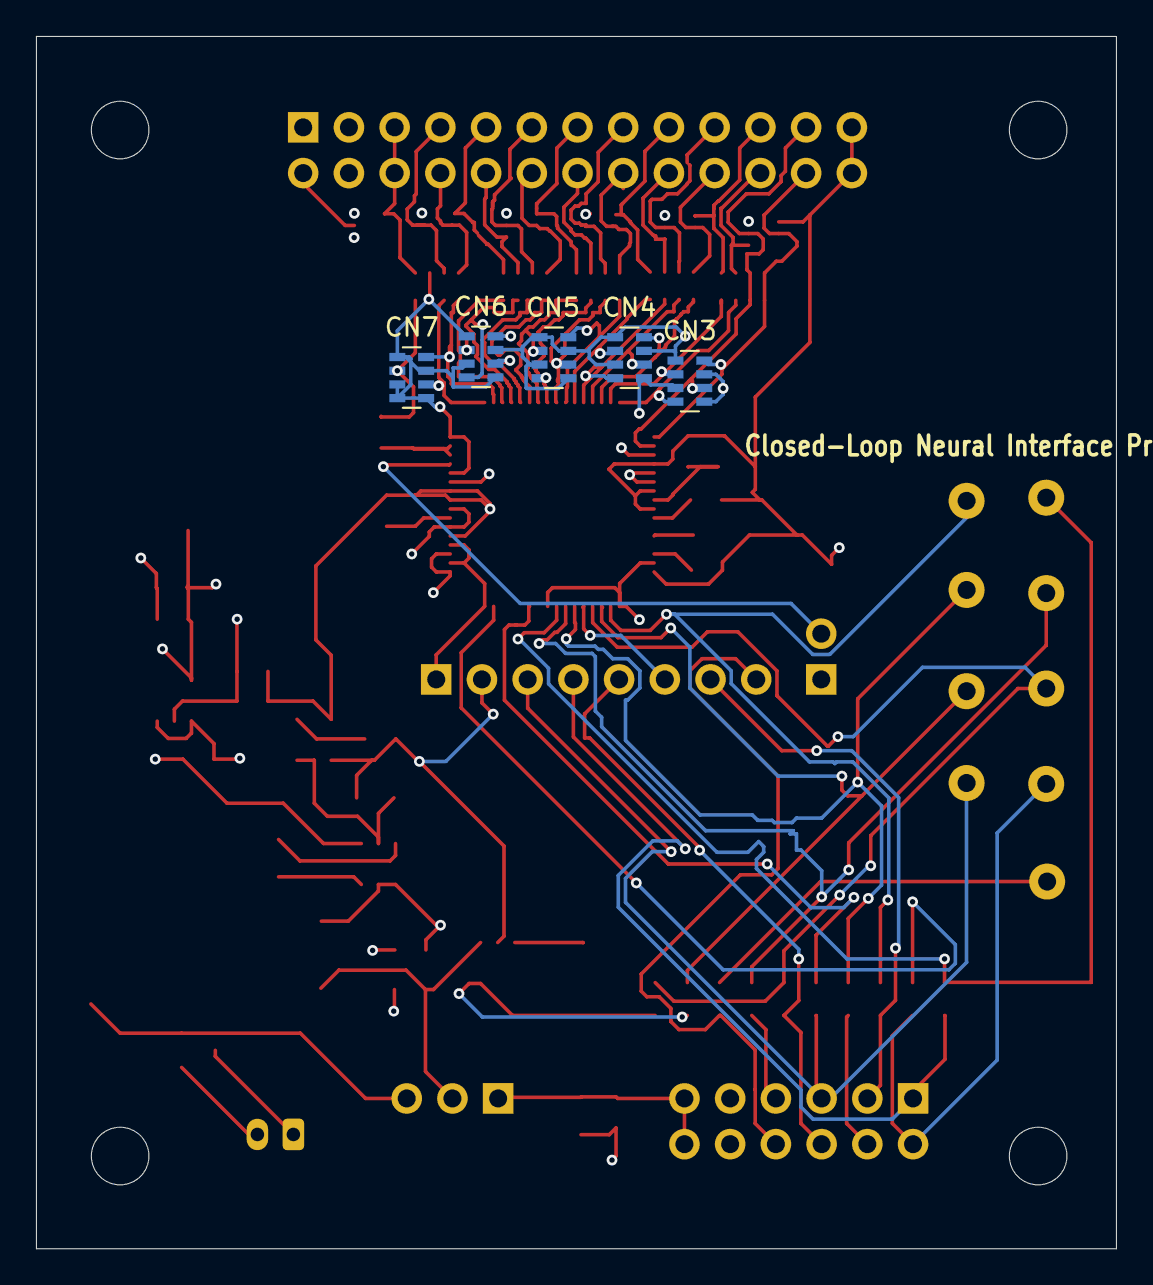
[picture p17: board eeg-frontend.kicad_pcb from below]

Board: 4 copper layers, 60.0 x 67.3 mm, 75 parts (5 on the bottom side), 74 nets.

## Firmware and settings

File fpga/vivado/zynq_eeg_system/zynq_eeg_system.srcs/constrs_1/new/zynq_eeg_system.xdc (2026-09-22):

## This file is a general .xdc for the ZYBO Rev B board
## To use it in a project:
## - uncomment the lines corresponding to used pins
## - rename the used signals according to the project


##Clock signal
#set_property -dict { PACKAGE_PIN L16   IOSTANDARD LVCMOS33 } [get_ports { clk }]; #IO_L11P_T1_SRCC_35 Sch=sysclk
#create_clock -add -name sys_clk_pin -period 8.00 -waveform {0 4} [get_ports { clk }];


##Switches
#set_property -dict { PACKAGE_PIN G15   IOSTANDARD LVCMOS33 } [get_ports { sw[0] }]; #IO_L19N_T3_VREF_35 Sch=SW0
#set_property -dict { PACKAGE_PIN P15   IOSTANDARD LVCMOS33 } [get_ports { sw[1] }];  #IO_L24P_T3_34 Sch=SW1
#set_property -dict { PACKAGE_PIN W13   IOSTANDARD LVCMOS33 } [get_ports { sw[2] }]; #IO_L4N_T0_34 Sch=SW2
#set_property -dict { PACKAGE_PIN T16   IOSTANDARD LVCMOS33 } [get_ports { sw[3] }]; #IO_L9P_T1_DQS_34 Sch=SW3


##Buttons
#set_property -dict { PACKAGE_PIN R18   IOSTANDARD LVCMOS33 } [get_ports { btn[0] }]; #IO_L20N_T3_34 Sch=BTN0
#set_property -dict { PACKAGE_PIN P16   IOSTANDARD LVCMOS33 } [get_ports { btn[1] }]; #IO_L24N_T3_34 Sch=BTN1
#set_property -dict { PACKAGE_PIN V16   IOSTANDARD LVCMOS33 } [get_ports { btn[2] }]; #IO_L18P_T2_34 Sch=BTN2
#set_property -dict { PACKAGE_PIN Y16   IOSTANDARD LVCMOS33 } [get_ports { btn[3] }]; #IO_L7P_T1_34 Sch=BTN3


##LEDs
set_property -dict { PACKAGE_PIN M14   IOSTANDARD LVCMOS33 } [get_ports { led[0] }]; #IO_L23P_T3_35 Sch=LED0
set_property -dict { PACKAGE_PIN M15   IOSTANDARD LVCMOS33 } [get_ports { led[1] }]; #IO_L23N_T3_35 Sch=LED1
set_property -dict { PACKAGE_PIN G14   IOSTANDARD LVCMOS33 } [get_ports { led[2] }]; #IO_0_35=Sch=LED2
set_property -dict { PACKAGE_PIN D18   IOSTANDARD LVCMOS33 } [get_ports { led[3] }]; #IO_L3N_T0_DQS_AD1N_35 Sch=LED3


##I2S Audio Codec
#set_property -dict { PACKAGE_PIN K18   IOSTANDARD LVCMOS33 } [get_ports ac_bclk]; #IO_L12N_T1_MRCC_35 Sch=AC_BCLK
#set_property -dict { PACKAGE_PIN T19   IOSTANDARD LVCMOS33 } [get_ports ac_mclk]; #IO_25_34 Sch=AC_MCLK
#set_property -dict { PACKAGE_PIN P18   IOSTANDARD LVCMOS33 } [get_ports ac_muten]; #IO_L23N_T3_34 Sch=AC_MUTEN
#set_property -dict { PACKAGE_PIN M17   IOSTANDARD LVCMOS33 } [get_ports ac_pbdat]; #IO_L8P_T1_AD10P_35 Sch=AC_PBDAT
#set_property -dict { PACKAGE_PIN L17   IOSTANDARD LVCMOS33 } [get_ports ac_pblrc]; #IO_L11N_T1_SRCC_35 Sch=AC_PBLRC
#set_property -dict { PACKAGE_PIN K17   IOSTANDARD LVCMOS33 } [get_ports ac_recdat]; #IO_L12P_T1_MRCC_35 Sch=AC_RECDAT
#set_property -dict { PACKAGE_PIN M18   IOSTANDARD LVCMOS33 } [get_ports ac_reclrc]; #IO_L8N_T1_AD10N_35 Sch=AC_RECLRC


##Audio Codec/external EEPROM IIC bus
#set_property -dict { PACKAGE_PIN N18   IOSTANDARD LVCMOS33 } [get_ports ac_scl]; #IO_L13P_T2_MRCC_34 Sch=AC_SCL
#set_property -dict { PACKAGE_PIN N17   IOSTANDARD LVCMOS33 } [get_ports ac_sda]; #IO_L23P_T3_34 Sch=AC_SDA


##Additional Ethernet signals
#set_property -dict { PACKAGE_PIN F16   IOSTANDARD LVCMOS33 } [get_ports eth_int_b]; #IO_L6P_T0_35 Sch=ETH_INT_B
#set_property -dict { PACKAGE_PIN E17   IOSTANDARD LVCMOS33 } [get_ports eth_rst_b]; #IO_L3P_T0_DQS_AD1P_35 Sch=ETH_RST_B


##HDMI Signals
#set_property -dict { PACKAGE_PIN H17   IOSTANDARD TMDS_33 } [get_ports hdmi_clk_n]; #IO_L13N_T2_MRCC_35 Sch=HDMI_CLK_N
#set_property -dict { PACKAGE_PIN H16   IOSTANDARD TMDS_33 } [get_ports hdmi_clk_p]; #IO_L13P_T2_MRCC_35 Sch=HDMI_CLK_P
#set_property -dict { PACKAGE_PIN D20   IOSTANDARD TMDS_33 } [get_ports { hdmi_d_n[0] }]; #IO_L4N_T0_35 Sch=HDMI_D0_N
#set_property -dict { PACKAGE_PIN D19   IOSTANDARD TMDS_33 } [get_ports { hdmi_d_p[0] }]; #IO_L4P_T0_35 Sch=HDMI_D0_P
#set_property -dict { PACKAGE_PIN B20   IOSTANDARD TMDS_33 } [get_ports { hdmi_d_n[1] }]; #IO_L1N_T0_AD0N_35 Sch=HDMI_D1_N
#set_property -dict { PACKAGE_PIN C20   IOSTANDARD TMDS_33 } [get_ports { hdmi_d_p[1] }]; #IO_L1P_T0_AD0P_35 Sch=HDMI_D1_P
#set_property -dict { PACKAGE_PIN A20   IOSTANDARD TMDS_33 } [get_ports { hdmi_d_n[2] }]; #IO_L2N_T0_AD8N_35 Sch=HDMI_D2_N
#set_property -dict { PACKAGE_PIN B19   IOSTANDARD TMDS_33 } [get_ports { hdmi_d_p[2] }]; #IO_L2P_T0_AD8P_35 Sch=HDMI_D2_P
#set_property -dict { PACKAGE_PIN E19   IOSTANDARD LVCMOS33 } [get_ports hdmi_cec]; #IO_L5N_T0_AD9N_35 Sch=HDMI_CEC
#set_property -dict { PACKAGE_PIN E18   IOSTANDARD LVCMOS33 } [get_ports hdmi_hpd]; #IO_L5P_T0_AD9P_35 Sch=HDMI_HPD
#set_property -dict { PACKAGE_PIN F17   IOSTANDARD LVCMOS33 } [get_ports hdmi_out_en]; #IO_L6N_T0_VREF_35 Sch=HDMI_OUT_EN
#set_property -dict { PACKAGE_PIN G17   IOSTANDARD LVCMOS33 } [get_ports hdmi_scl]; #IO_L16P_T2_35 Sch=HDMI_SCL
#set_property -dict { PACKAGE_PIN G18   IOSTANDARD LVCMOS33 } [get_ports hdmi_sda]; #IO_L16N_T2_35 Sch=HDMI_SDA
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

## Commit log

2026-07-29 Complete schematic before PCB layout
    [OpenBCI Daisy Designs.kicad_pcb, OpenBCI Daisy Designs.kicad_sch, ads1299.kicad_sch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]
2026-08-02 Assign footprints to schematic components
    [ads1299.kicad_sch, connectors.kicad_sch, eeg-frontend.kicad_pcb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]
2026-08-08 Arrange PCB component placement before routing
    [eeg-frontend.kicad_pcb]
2026-08-21 一旦できたと思ったPCB。 しかしPMODのコネクタの位置が左右で逆で、このまま刺すとGNDの一に通常のデータ信号的なのが来てしまう。
    [ads1299.kicad_sch, connectors.kicad_sch, eeg-frontend.kicad_pcb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]
2026-08-25 PCBレイアウトが完了
    [eeg-frontend.kicad_pcb, zynq_if.kicad_sch]
2026-08-30 PCBエディタ上に各部品のManufacturerとPart Number、とついでにDNP(実装するかどうか)を掲載した。
    [eeg-frontend.kicad_pcb]
2026-09-05 DigikeyでSAMSUNGのキャパシタが売り切れだったので村田のキャパシタに変更
    [eeg-frontend-CuBottom.gbr, eeg-frontend-CuIn1.gbr, eeg-frontend-CuIn2.gbr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]
2026-09-05 JLCPCBのガーバーを生成したら、git管理対象のファイルに違いが生じたのでとりあえずコミット
    [eeg-frontend-CuBottom.gbr, eeg-frontend-CuIn1.gbr, eeg-frontend-CuIn2.gbr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]
2026-09-22 Add Zynq PS to AXI GPIO LED control block design
2026-10-04 Add soldering implemented image
2026-10-04 Update soldering implemented image
2026-10-11 Add AXI GPIO LED control for PS-to-PL verification
2026-10-11 Add AXI GPIO LED control for PS-to-PL verification(FPGA)
2026-10-11 Add ADS1299 SPI receiver RTL and testbench
2026-10-16 Verify ADS1299 216-bit SPI frame reception on hardware
2026-10-16 Add & Verify AXI-Lite access to ADS1299 frame data
2026-10-19 feat: detect eye blinks from CH1 signal and trigger LED
2026-10-30 Add electrode_placement image
